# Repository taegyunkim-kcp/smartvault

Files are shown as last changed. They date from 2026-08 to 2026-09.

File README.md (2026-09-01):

# SmartVault (NFC Smart Vault MIL-S)

군부대 내무반용 스마트폰 보관함 IoT 시스템. 모노레포 구조.

## 레포 구조

```
smartvault/
├── hardware/          # 게이트웨이 보드 KiCad 프로젝트 (회로도/PCB)
├── firmware/          # Arduino MCU 펌웨어 (RFID×10 리더, 잠금장치 제어)
├── gateway-bridge/    # 건물별 Concentrator - RS485 ↔ 중앙서버 브리지 (Python)
├── backend/           # API 서버 (Node/Express + MySQL)
├── frontend/          # 관리자 대시보드 (React)
└── docs/              # 아키텍처/온보딩/프로토콜/설계 문서
```

## 개발 시작하기 (Windows)

자세한 설치 절차는 `docs/dev-environment-setup.md` 참고. 요약:

```powershell
# 1. DB 컨테이너 기동 (개발용)
docker compose -f docker-compose.dev.yml up -d

# 2. 백엔드
cd backend
copy .env.example .env.development
npm install
npm run dev

# 3. 프론트엔드
cd ../frontend
npm install
npm run dev
```

## 개발/운영 환경 분리 원칙

이 PC 한 대에서 개발과 운영을 동시에 돌립니다. **절대 같은 포트·같은 DB를 쓰지 않습니다.**

| | 개발(dev) | 운영(prod) |
|---|---|---|
| 백엔드 포트 | 4000 | 4001 |
| 프론트엔드 포트 | 3000 (vite dev server) | 3001 (정적 빌드 서빙) |
| DB 포트 | 3307 (Docker) | 3308 (Docker) |
| DB 이름 | smartvault_dev | smartvault_prod |
| 환경변수 파일 | `.env.development` | `.env.production` |
| 실행 방식 | `npm run dev` (터미널, 코드 수정 시 자동 재시작) | PM2로 백그라운드 상시 구동 |

자세한 내용은 `docs/dev-environment-setup.md` 참고.

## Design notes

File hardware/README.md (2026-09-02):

# hardware — 보관함 게이트웨이 KiCad 프로젝트

Arduino UNO 게이트웨이 보드의 회로도/PCB 원본. 같은 디렉토리의 `CLAUDE.md`가 이
설계를 검토·확정한 뒤 요약한 문서이므로, **핀맵/넷 이름 등은 그 문서를 표준으로 삼고**,
실제 배선의 세부(부품값, 커넥터 핀아웃 등)를 확인할 땐 여기 KiCad 파일을 연다.

## 구성

- `kicad/smartvault.kicad_pro` — 프로젝트 파일, KiCad로 이걸 연다.
- `kicad/smartvault.kicad_sch` — 최상위 시트. 아래 서브시트를 계층적으로 포함:
  - `DEVid-Buzz.kicad_sch` — 74HC165 장치ID + 부저
  - `DoorRock-drv.kicad_sch` — 도어락 구동
  - `MFRC522_Conn.kicad_sch` — RFID 리더 10개 커넥터 + 74LVC138A 디코더 뱅크
  - `power.kicad_sch` — 12V→5V/3.3V 전원부
  - `RS485-com.kicad_sch` — MAX13487E RS485 트랜시버
  - `RST-wDog.kicad_sch` — ATtiny13A 워치독/리셋 회로
- `kicad/smartvault.kicad_pcb` — PCB 레이아웃(아직 초기 단계 — 배치/라우팅 미완료일 수 있음)
- `kicad/s_vault.kicad_sym` — 커스텀 심볼 라이브러리(이 프로젝트 전용으로 그린 부품 심볼).
  원본: `D:\pcb\smartvault-pcb-1\s_vault.kicad_sym`. `RS485-com.kicad_sch`/`power.kicad_sch`가
  이 라이브러리의 심볼을 참조한다.
- `kicad/footprint.xlsx` — 부품-풋프린트 매핑 스프레드시트(2026-09-02 추가)

## 원본 출처

**작업은 이 PC의 `D:\pcb\회로도 편집 완료\`에서 KiCad로 직접 한다.** `Z:\HDD2\pcb 설계\`는
집 밖에서 작업할 때 쓰는 공유 드라이브로, D:의 내용을 그대로 미러링한다 — 두 경로
내용이 다르면 **D:을 기준으로 삼을 것**(2026-09-02 확정).

현재 버전(2026-09-02 기준): `D:\pcb\회로도 편집 완료\20260901_ver01\`. 원본 프로젝트
파일명은 `20260901_ver01.kicad_*`이지만, 저장소 안에서는 계속 `smartvault.kicad_*`로
통일했다(작업 폴더에 날짜/버전을 붙이는 건 원본 쪽 관례일 뿐 — git이 버전을 관리하므로
저장소 파일명까지 따라 바꾸지 않는다. 파일 내부에 프로젝트명을 참조하는 부분
(`(project "...")`, `.kicad_pro`의 filename 필드 등)은 전부 `smartvault`로 바꿔서
복사했다).

원본 작업 폴더 이름 자체가 버전마다 바뀌어왔다(`smartvault-pcb-1/smartvault/` →
`회로도 편집 완료/20260901_ver01/`) — 다음에 갱신할 때 폴더 구조가 또 바뀌었을 수
있으니 `D:\pcb\` 아래를 먼저 훑어서 최신 폴더를 확인할 것.

**이 저장소의 사본은 스냅샷이다** — 실제 설계가 바뀌면 원본에서 다시 복사해서 갱신해야
하고, 그때마다 같은 디렉토리의 `CLAUDE.md`도 같이 확인해서 핀맵이 안 어긋나게 맞출 것
(`CLAUDE.md` 7장 "변경 이력 관리 원칙" 그대로 적용).

상세 설계 문서(회로도 이미지 포함)는 `docs/SmartVault_Design_Document.docx`도 같이 참고.

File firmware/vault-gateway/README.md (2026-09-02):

# vault-gateway — 보관함 게이트웨이(Arduino UNO) 펌웨어

내무반 1개당 1대 설치되는 컨트롤러 보드 펌웨어. 핀맵/하드웨어 확정 스펙은
`hardware/CLAUDE.md` 1장을 따른다 — 핀 번호를 바꿔야 하면 그 문서를 먼저 고치고 `pins.h`를 맞출 것.

## 레거시 참고 코드

`Z:\HDD2\스마트폰보관함\1. 일반\mcuProgram\ver1_2_1_close_reading_only_white_MCU_20250204`
(가장 최신 버전, 파일명 날짜 기준)가 실전에서 쓰인 이전 보드 펌웨어다. 여기서 실제로
가져온 값/로직:
- 도어락 개방 펄스 2000ms, LOCK_STATE 극성(LOW=닫힘) — `door_lock.cpp`
- 버튼은 "지금 닫혀 있을 때만" 먹는다 — `door_lock.cpp`
- 카드 인식 멜로디(G7,G7,G5,G5 각 ~31ms) — `buzzer.cpp`
- 내장 AVR 워치독(`wdt_enable(WDTO_2S)`, RS485 바이트 수신 시에만 `wdt_reset()`) — `vault-gateway.ino`

의도적으로 안 가져온 것: 리더 CS 방식(레거시는 리더당 GPIO 10개 직결, 이 보드는
74LVC138A 디코더라 배선 자체가 다름)과 통신 프레임 포맷(레거시는 가변 구분자 텍스트,
여기는 고정 길이+체크섬으로 재설계 — `docs/architecture.md` 5장이 원래 그렇게 하라고
명시한 부분).

## 상태 (v0 초안, 2026-09-02)

**컴파일 확인 완료** — `arduino-cli` 1.5.1 + `arduino:avr` 1.8.8 + `MFRC522` 1.4.12로
`arduino:avr:uno` 대상 컴파일, `--warnings all`에서도 경고 0개. 스케치 9894바이트(30%),
전역변수 488바이트(23%) 사용. 재현하려면:

```powershell
arduino-cli core install arduino:avr
arduino-cli lib install MFRC522
arduino-cli compile --fqbn arduino:avr:uno --warnings all firmware/vault-gateway
```

컴파일만 확인한 것이고 **실제 보드에서 동작을 검증한 적은 없음** — RFID 리더/도어락 없이는
`rfid_mux`/`door_lock`이 실제 하드웨어와 맞물려 도는지 알 수 없다. 업로드 전 벤치 테스트 필수.

## 필요한 라이브러리 (Arduino IDE 라이브러리 매니저)

- `MFRC522` (miguelbalboa/rfid) — RFID 리더 제어
- `SoftwareSerial`, `SPI` — 아두이노 코어 내장, 별도 설치 불필요

## 보드 설정

- 보드: Arduino UNO
- 업로드: USB(소켓 마운트된 UNO에 직접) — PlatformIO 아님, Arduino IDE로 이 폴더를 스케치로 열기

## 모듈 구성

| 파일 | 역할 |
|---|---|
| `pins.h` | 핀맵 상수 (근거: hardware/CLAUDE.md 1장) |
| `gateway_identity.h` | **설치자가 직접 편집**하는 `GATEWAY_GROUP_ID`(2글자) — DIP주소와 합쳐 4글자 게이트웨이 ID를 만든다 |
| `device_id.*` | 74HC165 DIP 스위치 8비트 읽기 (부팅 시 1회) |
| `rfid_mux.*` | 74LVC138A 디코더로 리더 선택. **"새 카드 이벤트"가 아니라 "지금 상태 조회"** — 호출될 때마다 그 리더를 재초기화해서 계속 거치 중인 카드도 매번 다시 감지되게 함(스마트폰이 슬롯에 몇 시간씩 거치돼 있어도 실시간 상태를 알아야 하므로). **MFRC522 라이브러리의 SS 핀 토글은 실제 배선과 무관** — 진짜 선택은 이 모듈이 디코더 주소로 미리 해둔다 |
| `rs485_link.*` | 집중장치와의 프레임 송수신. **명령 없이 스스로 아무것도 안 보냄**(자동 하트비트 없음 — 여러 게이트웨이가 한 버스를 쓰므로 버스 충돌 방지). `READEROP='R'`로 콕 집어 물어볼 때만 도어 상태+리더 상태를 한 번에 응답, 브로드캐스트로 온 'R'은 무시. check_in/check_out 판단은 안 하고 현재 상태만 보고, 부저도 안 울림(서버 보고용과 로컬 확인음은 별개) (`firmware/docs/protocol-spec.md` 참고) |
| `door_lock.*` | 도어락 구동/버튼/센서, **fail-secure 정책** (통신 두절 시 무조건 잠금). 펄스 길이/극성/버튼 가드는 레거시에서 검증된 값 |
| `presence_watch.*` | 문이 열려 있는 동안 **게이트웨이가 스스로** 리더를 순회하며, 빈 자리에 폰이 새로 놓이는 순간에만 확인 부저(뺄 땐 무음). RS485/서버와 무관한 순수 로컬 로직이라 통신 두절 중에도 동작 |
| `buzzer.*` | 부저 — 카드 인식 멜로디는 레거시 값 그대로, 나머지는 placeholder |
| `vault-gateway.ino` | `setup()`/`loop()` — 위 모듈을 엮음. 내장 AVR 워치독도 여기서 관리 |

## 알려진 미해결 항목

1. **실제 하드웨어에서는 미검증** — 컴파일만 확인됨(위 참고). 실물 리더/락 붙여서 동작 테스트 필요.
2. **ATtiny13A 워치독 펌웨어** — 완전히 별개 프로젝트(ISP로 직접 굽고 소켓에 꽂음, 여기 스케치와 무관). 아직 시작 안 함.
3. **도어락 펄스/센서 극성 재확인 권장** — 레거시 값(2000ms, LOW=닫힘)을 그대로 가져왔지만, 배선판이 바뀐 새 보드에서 벤치로 한 번은 재확인 권장(`door_lock.cpp` 상단 주석).
4. **RESET 필드(전체 재부팅류) 미연결** — 프로토콜상 파싱은 하지만 아직 실제 동작에 안 이어짐(`rs485_link.cpp`의 `(void)resetScope`).
5. **집중장치(`gateway-bridge/`) 쪽 파서 + check_in/check_out diff 로직 미구현** — 지금 이 펌웨어가 보내는 `:RD:...:PRESENT:...` 응답을 실제로 받아서 리더별 마지막 상태와 비교해 입고/출고 전환을 만드는 코드가 반대편에 아직 없다(`bridge/protocol_parser.py` 없음). 이 diff는 **집중장치가 기본 담당**, 서버 이벤트 관리와 연계해서 확장 가능하게 만들기로 확정(2026-09-02).
6. **개방/오류 부저 톤** — placeholder(레거시엔 대응 패턴 없음). 카드 인식 멜로디만 레거시 검증값.
7. **폴링 주기/명령 간격 실측 필요** — `protocol-spec.md`의 타이밍 수치는 보레이트 계산만 한 추정치, 실물 리더 스캔 시간 미측정.

## 게이트웨이 ID ↔ gateway_id 매핑 (2026-09-02 확정, 상세는 protocol-spec.md)

DIP 스위치(8비트)만으로는 버스 하나 안에서만 유일해서, `gateway_identity.h`의
`GATEWAY_GROUP_ID`(설치자가 하드웨어/펌웨어 배치별로 편집하는 2글자 상수)와 합쳐
4글자 원시 ID를 만들어 RS485로 전달한다. 이건 최종 `gateway_id`(`"1CORPS-B3-R204-G1"`
같은 문자열)가 아니다 — **로컬 설정 파일로 미리 매핑을 만들어두지 않는다.** 대신 이미
있는 관리자 등록 플로우(`detected_gateways` → `GatewayListPage.jsx`에서 매칭 → `gateways`
정식 등록)를 그대로 재사용한다: 집중장치는 미등록 원시 ID를 그대로 서버에 올리고,
관리자가 방과 매칭하면 그 결과를 집중장치가 캐시해서 이후 보고에 쓴다. 이 캐싱/동기화
로직 자체는 아직 `gateway-bridge` 쪽에 없다(다음 단계).

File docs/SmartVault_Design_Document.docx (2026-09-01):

SmartVault — NFC/RFID 스마트폰 보관함 잠금장치

전체 회로도 설계 문서 (KiCad 실제 회로 기준) | Rev. B | 2026-09-01

본 문서는 KiCad로 작성된 실제 회로도(루트 시트 + 6개 서브시트)를 기준으로 설계 의도와 동작 원리를 정리한 것입니다. 각 시트별로 회로 설명과 BOM을 수록하고, 문서 마지막에 전체 부품을 지정자순으로 통합한 BOM을 별도로 정리했습니다.

# 1. 시스템 종합 개요

## 1.1 용도 및 전체 구성

이 보드는 다수의 스마트폰 보관함(사물함)에 하나씩 설치되는 컨트롤러로, RS485 멀티드롭 버스로 상위 서버와 통신하며 다음 기능을 수행합니다: ① NFC/RFID 카드로 보관함 슬롯(최대 10개) 사용자 인식, ② 전자 도어락 개폐 제어 및 상태 감지, ③ RS485를 통한 서버와의 명령/응답 송수신, ④ 통신 두절 시 자동 복구(워치독), ⑤ DIP 스위치를 통한 현장 설정(장치 ID, RS485 종단/바이어스, 도어락 전압).

두뇌 역할은 Arduino UNO(소켓 마운트)가 담당하며, 보조로 ATtiny13A 기반 워치독 MCU가 UNO의 무응답을 감시합니다. 전원은 12V 어댑터 하나로 입력받아 보드에서 5V/3.3V를 자체 생성합니다.

## 1.2 전체 신호 흐름

12V_IN → [Sheet1 전원부] → 5V_RAW / 3V3_RAW 생성 → Arduino UNO(MCU) → 각 서브시스템(Sheet2 도어락, Sheet3 RS485, Sheet5 RFID×10, Sheet6 장치ID/부저) 제어 → Sheet4 워치독이 RS485 수신 활동을 감시하며 무응답 시 UNO를 리셋/재부팅

## 1.3 핵심 설계 원칙

- 무인 운영 안정성 — 2단계 워치독: RS485 수신 활동이 일정 시간 끊기면 1단계로 UNO를 소프트 리셋(RESET 핀 풀다운)하고, 그래도 복구되지 않으면 2단계로 전원 자체를 완전히 껐다 켜는 콜드리셋을 수행합니다(Sheet1의 로드스위치 Q1을 Sheet4의 H_Reset 신호로 제어).
- 아두이노 핀 절약 — RFID 리더 10개의 칩셀렉트(CS)를 74LVC138A 디코더 2개로 압축해 4핀(주소 3비트+뱅크선택)만 사용하고, 장치 ID(8비트)는 74HC165 시프트레지스터로 3핀만 사용합니다. 그 결과 UNO 20핀 예산 안에서 모든 기능을 수용하면서도 D10 등 여유 핀이 남습니다.
- 현장 설정 가능성 — RS485 종단저항(SW2)과 바이어스(SW3/SW4), 도어락 구동전압(SW1, 5V/12V 선택)을 전부 하드웨어 스위치로 두어, 설치 현장에서 펌웨어 재업로드 없이 구성을 맞출 수 있습니다.
- 유지보수성 — Arduino UNO와 워치독 MCU(ATtiny13A) 모두 소켓 마운트입니다. UNO는 USB로 직접 업로드하고, ATtiny13A는 별도 ISP 프로그래머로 미리 구운 뒤 소켓에 꽂아 사용해 보드에 별도 ISP 헤더가 필요 없습니다.
- 신호 무결성 — 5V(UNO)↔3.3V(MFRC522) 레벨 차이는 채널별 독립 트라이스테이트 버퍼(74LVC125A, 74AHCT1G125)로 처리해, 옥탈 트랜시버 한 개로 방향을 공유할 때 생기는 제약을 피했습니다. 모든 신호선에는 직렬저항을 두어 반사·노이즈에 대비했습니다.

# 2. Sheet 1 — 전원부 (power Sheet)

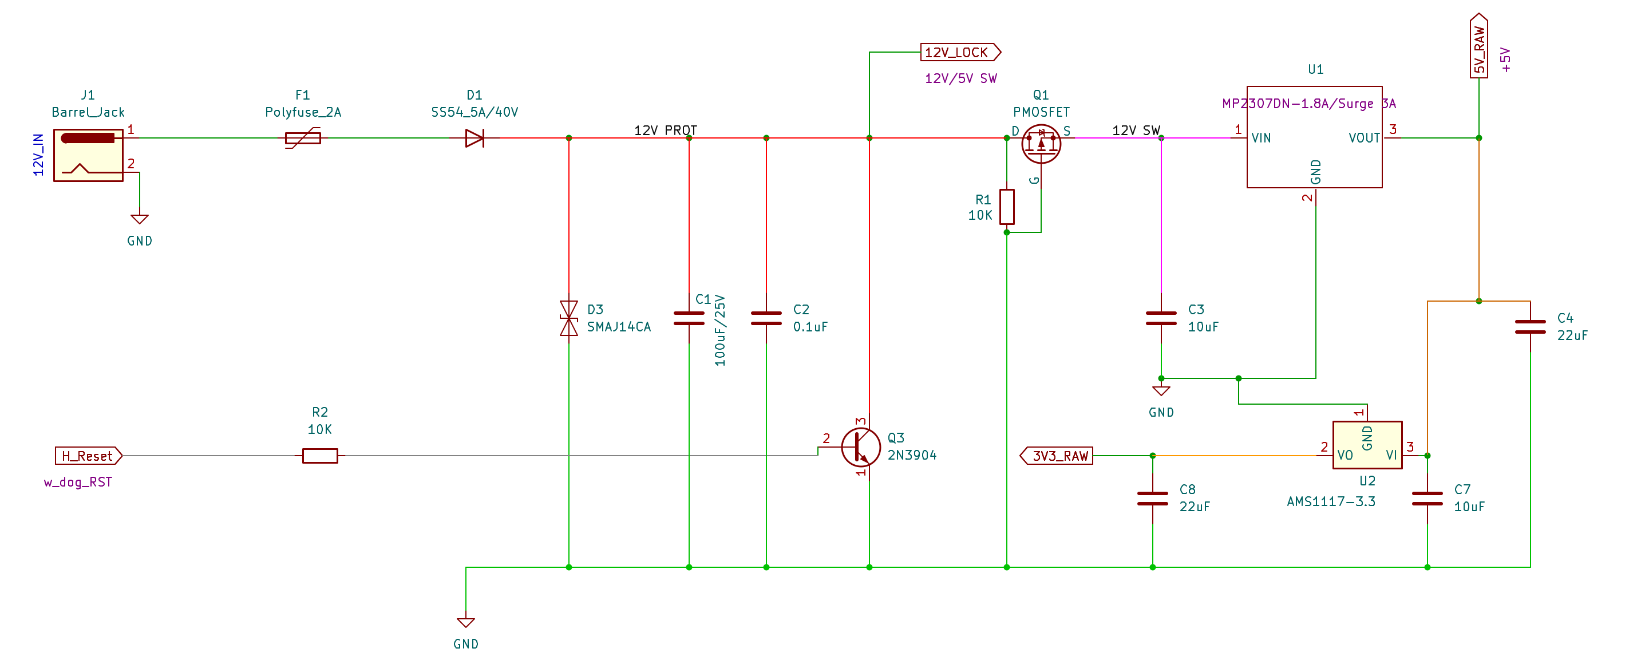
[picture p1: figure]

## 설계 설명

12V 어댑터 입력(J1)을 F1(2A 폴리퓨즈)과 D1(쇼트키, 역전압 방지)로 1차 보호한 뒤, D3(양방향 TVS)로 서지를 흡수하고 C1/C2로 벌크·고주파 디커플링을 한 넷이 12V_PROT입니다. 12V_LOCK은 이 12V_PROT 지점에서 곧바로 분기되므로, 뒤에 있는 로드스위치(Q1)가 꺼지더라도 도어락 전원은 항상 살아있습니다 — 콜드리셋 도중에도 도어락 상태가 끊기지 않도록 하기 위한 설계입니다.

Q1(P-MOSFET)은 12V_PROT과 12V_SW 사이의 로드스위치로, Q3(NPN)를 통해 워치독 신호(H_Reset)로 On/Off됩니다. H_Reset이 HIGH(평상시)면 Q3가 켜져 Q1 게이트가 LOW로 당겨져 Q1이 On되고, H_Reset이 LOW(워치독 2단계 트리거)가 되면 Q1이 Off되어 U1/U2 이후 전체 로직 전원이 완전히 차단됐다가 다시 켜집니다 — 진짜 콜드리셋입니다.

12V_SW는 U1(MP2307DN, 1.8A 지속/3A 서지 벅컨버터)에서 5V_RAW로 변환되고, 이 5V_RAW가 U2(AMS1117-3.3 LDO)를 거쳐 3V3_RAW가 됩니다. 5V_RAW는 UNO의 5V 핀에 직결(VIN 미사용)되어 온보드 리니어 레귤레이터의 발열을 피하고, 3V3_RAW는 MFRC522 10개 전용 전원으로 UNO 온보드 3.3V(약 50mA 한계)를 대체합니다.

## BOM

지정자 | 부품 | 정격/값 | 비고
J1 | DC 배럴잭 | Barrel_Jack | 12V_IN 입력
F1 | 폴리퓨즈 | 2A | 과전류 보호
D1 | 쇼트키 다이오드 | SS54 (5A/40V) | 역전압 보호
D3 | 양방향 TVS 다이오드 | SMAJ14CA | 서지 보호
C1 | 전해커패시터 | 100uF/25V | 12V 벌크 커패시턴스
C2 | 세라믹커패시터 | 0.1uF | 고주파 디커플링
Q1 | P채널 MOSFET | PMOSFET | 고전위측 로드스위치(콜드리셋)
R1 | 저항 | 10K | Q1 게이트 풀업
Q3 | NPN 트랜지스터 | 2N3904 | H_Reset 신호 반전 구동
R2 | 저항 | 10K | Q3 베이스 전류 제한
U1 | DC-DC 벅컨버터 | MP2307DN (1.8A 지속/3A 서지) | 12V→5V
C3 | 세라믹커패시터 | 10uF | U1 입력(VIN) 디커플링
C4 | 세라믹커패시터 | 22uF | U1 출력(5V_RAW) 디커플링
U2 | 3.3V LDO 레귤레이터 | AMS1117-3.3 | 5V_RAW→3V3_RAW
C5 | 세라믹커패시터 | 10uF | U2 입력(VI) 디커플링
C6 | 세라믹커패시터 | 22uF | U2 출력(VO/3V3_RAW) 디커플링

# 3. Sheet 2 — 도어락 구동부 (DoorRock-drv)

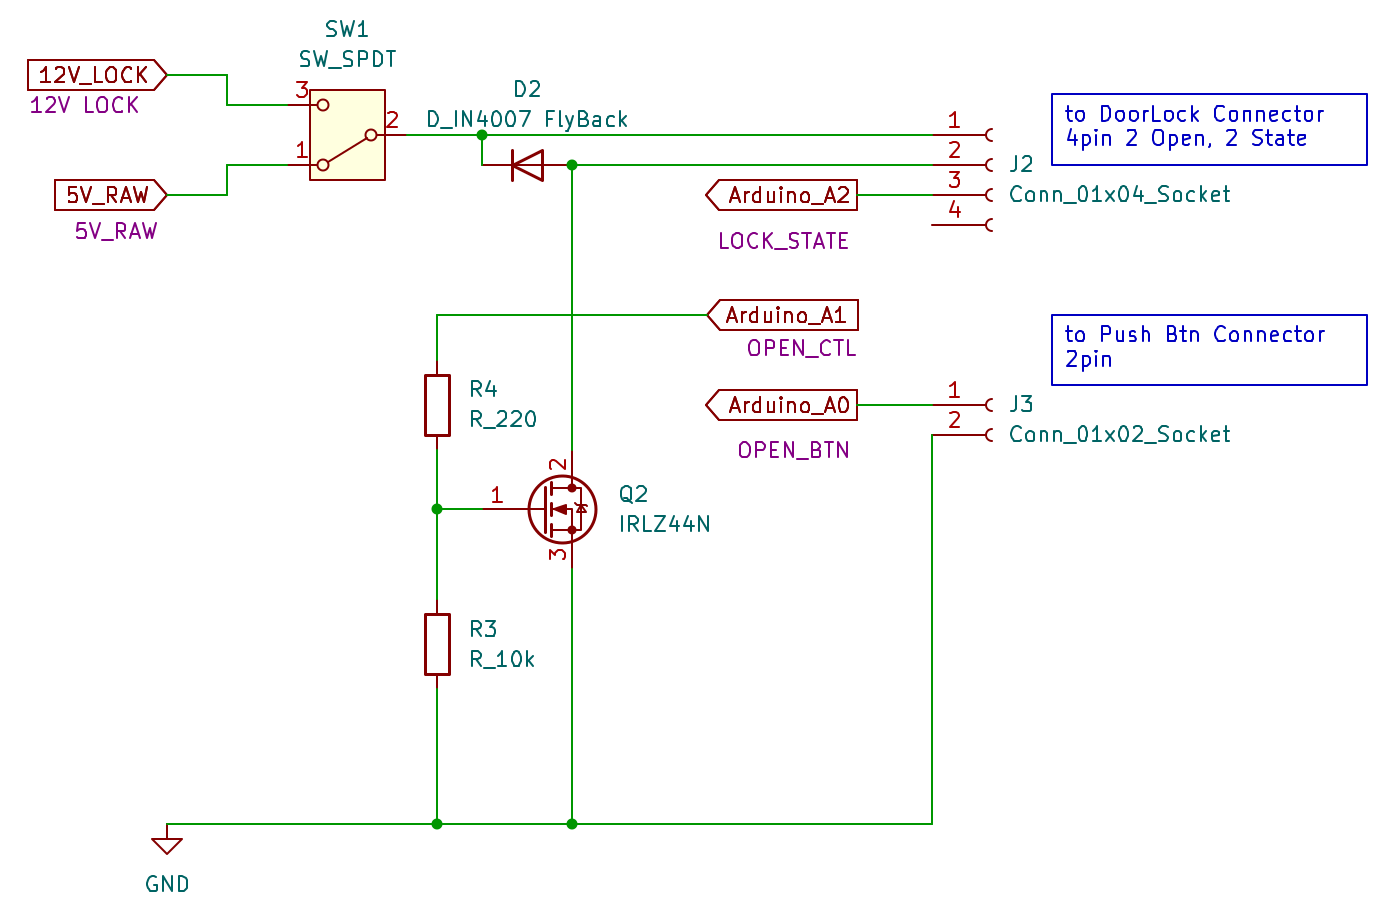
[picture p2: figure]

## 설계 설명

SW1(SPDT)로 도어락 구동전압을 12V_LOCK 또는 5V_RAW 중 하나로 설치 시 선택합니다. Q2(IRLZ44N, 로직레벨 N-MOSFET)가 저전위측 스위치로 도어락 솔레노이드를 구동하며, R4(220Ω)는 게이트 전류 제한, R3(10K)는 게이트 풀다운으로 부팅·리셋 중 하이임피던스 상태에서도 도어락이 오픈(오동작)되지 않도록 합니다. D2(1N4007)는 솔레노이드 역기전력을 흡수하는 플라이백 다이오드입니다.

J2(4핀)는 실제 도어락 어셈블리(솔레노이드+상태감지 스위치가 물리적으로 하나의 장치)로 나가는 커넥터로, LOCK 구동선 2개와 LOCK_STATE(상태감지, →A2) 및 GND로 구성됩니다. J3(2핀)는 로컬 개방 버튼(→A0)입니다. OPEN_CTL(A1)이 Arduino에서 Q2 게이트로 나가는 제어 신호이며, LOCK_STATE와 OPEN_BTN은 INPUT_PULLUP으로 별도 풀업저항 없이 스위치를 GND로 직결하는 방식입니다.

## BOM

지정자 | 부품 | 정격/값 | 비고
SW1 | 전압 선택 스위치 | SW_SPDT | 12V_LOCK ↔ 5V_RAW 중 1개 선택 — 동시 인가 금지
D2 | 정류 다이오드 | 1N4007 | 플라이백(역기전력) 보호
R4 | 저항 | 220Ω | Q2 게이트 전류 제한
R3 | 저항 | 10K | Q2 게이트 풀다운 — 부팅 중 오픈 방지
Q2 | N채널 로직레벨 MOSFET | IRLZ44N | 도어락 구동 스위치
J2 | 4핀 소켓 커넥터 | Conn_01x04_Socket | DoorLock — LOCK+/LOCK_RTN/LOCK_STATE(→A2)/GND
J3 | 2핀 소켓 커넥터 | Conn_01x02_Socket | Push Btn — OPEN_BTN(→A0)/GND

# 4. Sheet 3 — RS485 통신부 (RS485-com)

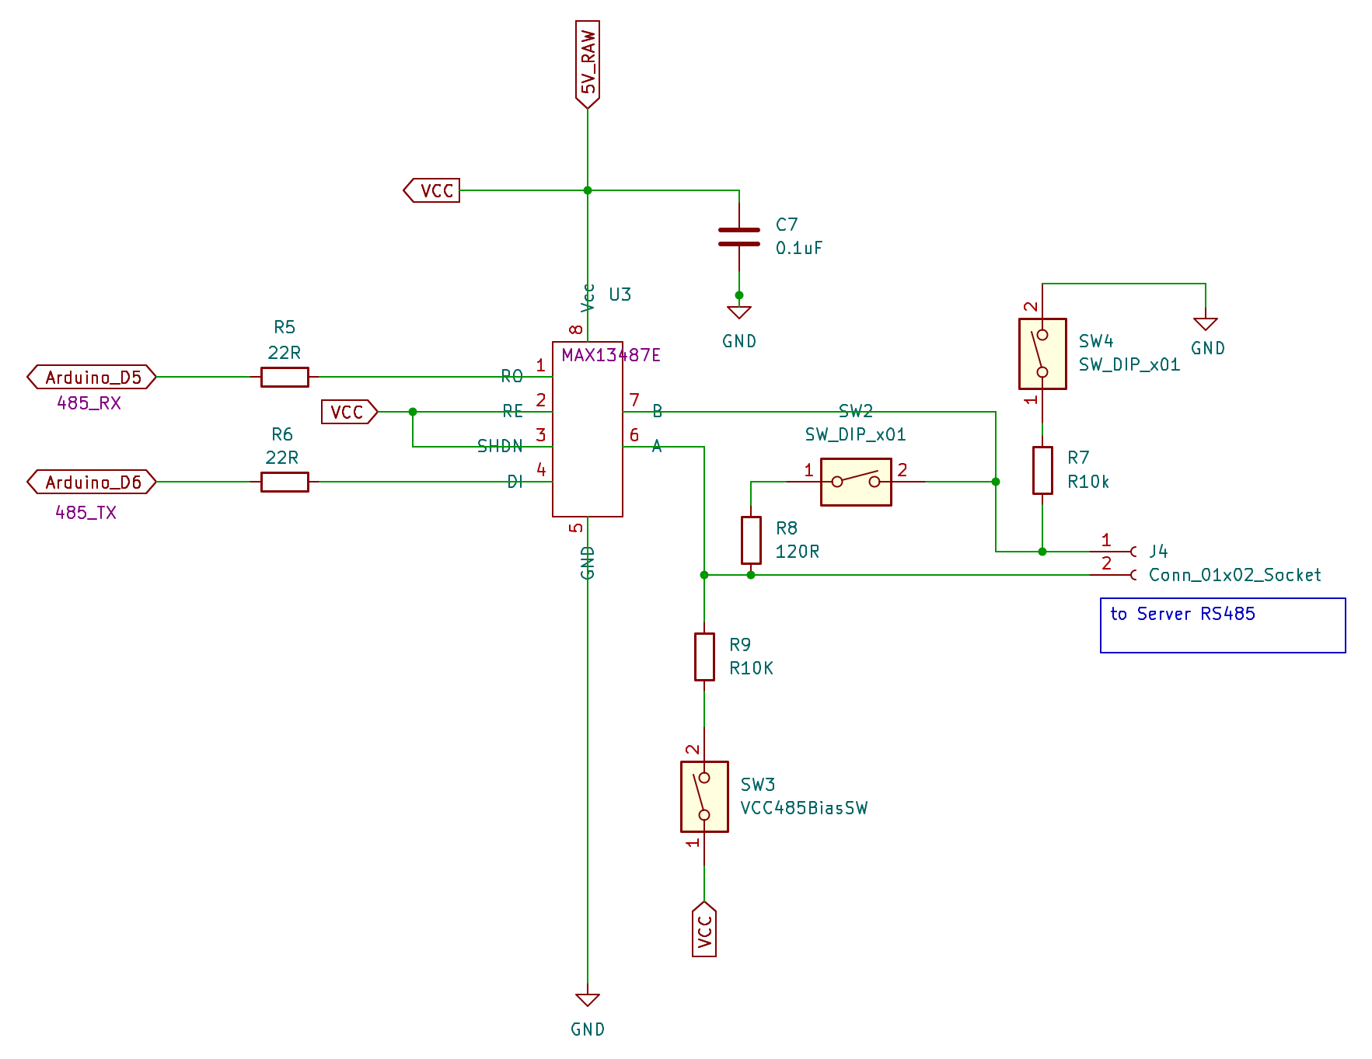
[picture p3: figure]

## 설계 설명

U3(MAX13487E)는 AutoDirection 기능이 내장된 RS485 트랜시버로, RE#·SHDN# 핀을 모두 VCC에 고정해두면 칩 내부 상태머신이 DI(송신 데이터) 활동을 스스로 감지해 버스 방향전환을 자동 처리합니다 — Arduino가 별도 GPIO로 방향을 제어할 필요가 없습니다. Arduino의 485_RX(D5)/485_TX(D6)는 R5/R6(22Ω)을 거쳐 U3의 RO/DI에 연결되며, C7(0.1uF)이 U3 VCC 바로 옆에서 디커플링을 담당합니다.

이 보드는 여러 보관함이 하나의 RS485 버스에 멀티드롭으로 물리는 구조이므로, 종단저항과 페일세이프 바이어스는 버스 전체에서 딱 한 곳(들)에만 필요합니다. R8(120Ω)이 A-B 사이의 종단저항이며 SW2(DIP)로 유효/무효화합니다 — 버스 양 끝단 노드만 켭니다. R9(10K, A라인→VCC 풀업)는 SW3으로, R7(10K, B라인→GND 풀다운)은 SW4로 각각 독립적으로 활성화하는데, 이 역시 버스 여러 노드 중 바이어스를 담당할 한 곳에서만 켜서 과도한 부하 없이 유휴 시 정형화된 유휴 전압을 유지합니다. J4가 실제 RS485 버스(서버 방향)로 나가는 A/B 2핀 커넥터입니다.

## BOM

지정자 | 부품 | 정격/값 | 비고
U3 | RS485 트랜시버 | MAX13487E | RE#/SHDN# 모두 VCC 고정, AutoDirection
R5 | 저항 | 22Ω | RO 직렬(신호보호)
R6 | 저항 | 22Ω | DI 직렬(신호보호)
C7 | 세라믹커패시터 | 0.1uF | U3 VCC 디커플링
R8 | 저항 | 120Ω | 버스 종단(A-B 간) — SW2로 유효화
R9 | 저항 | 10K | A라인 풀업 바이어스 — SW3로 인에이블
R7 | 저항 | 10K | B라인 풀다운 바이어스 — SW4로 인에이블
SW2 | DIP 스위치(1P) | SW_DIP_x01 | 종단저항 유효화 — 버스 끝단 노드만 ON
SW3 | 스위치(1P) | VCC485BiasSW | A라인 바이어스 인에이블 — 담당 노드만 ON
SW4 | DIP 스위치(1P) | SW_DIP_x01 | B라인 바이어스 인에이블 — 담당 노드만 ON
J4 | 2핀 소켓 커넥터 | Conn_01x02_Socket | to Server RS485 (A/B)

# 5. Sheet 4 — 리셋 / 워치독 (RST-wDog)

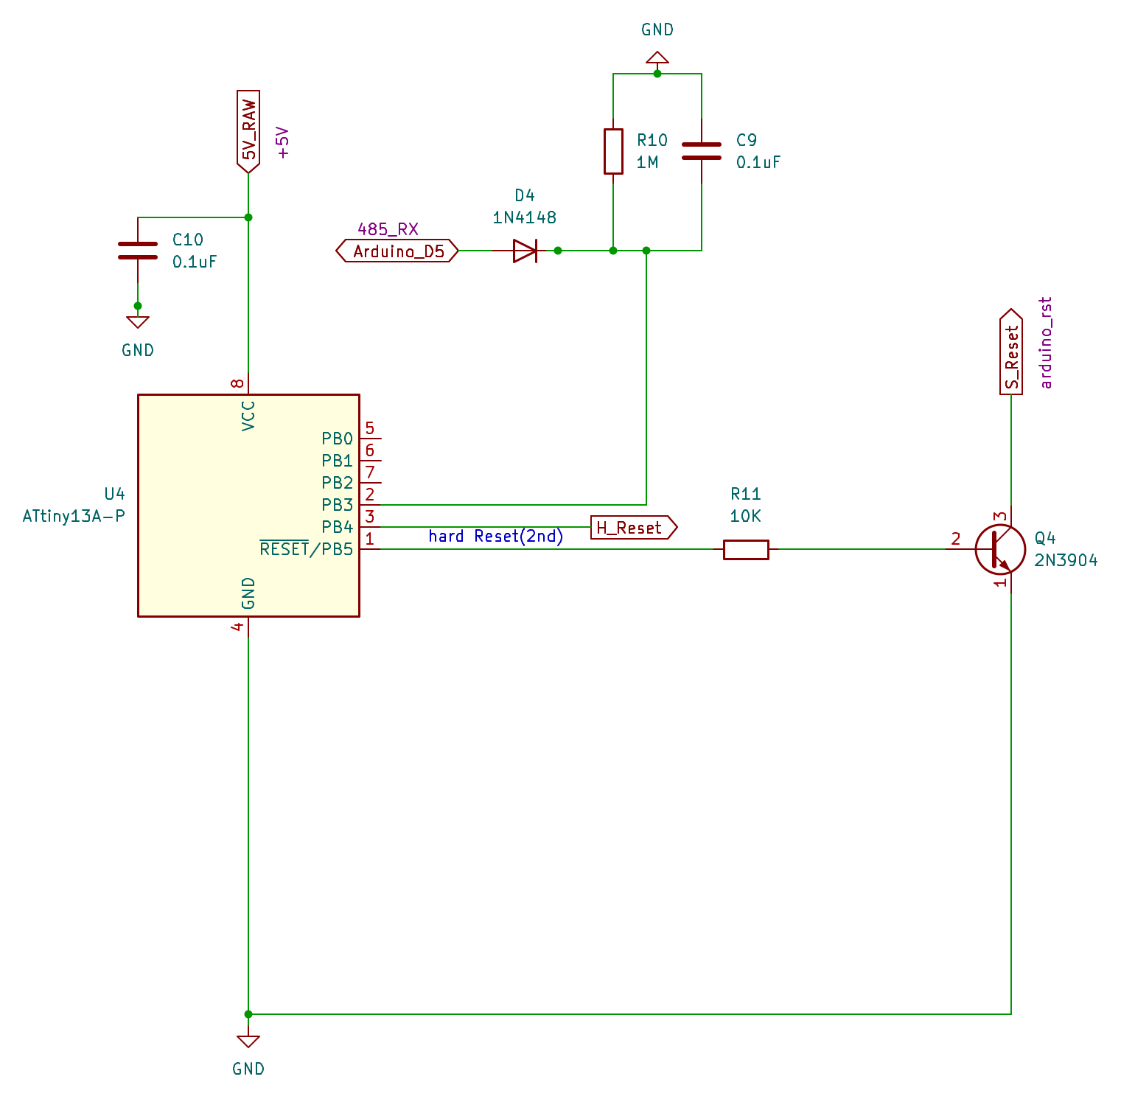
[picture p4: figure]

## 설계 설명

D4(1N4148)+R10(1M)+C9(0.1uF)는 485_RX(D5, RS485 수신선)의 펄스 활동을 감지하는 간이 피크검출 회로입니다. 통신 펄스가 들어올 때마다 C9가 충전되고, 일정 시간 펄스가 없으면 R10을 통해 서서히 방전됩니다. U4(ATtiny13A-P)가 이 전압(PB3)을 아날로그로 주기적으로 읽어, 전압이 임계값 밑으로 떨어지면(=한동안 통신이 없었다는 뜻) '무응답'으로 판단합니다.

2단계 대응 로직입니다. 1단계: 무응답 판정 시 U4의 PB4(H_Reset 넷)를 통해 자체적으로 처리하거나, PB5(RESET 겸용)를 통해 R11(10K)→Q4(2N3904)를 거쳐 Arduino의 RESET 핀(arduino_rst)을 짧게 풀다운해 소프트 리셋을 시도합니다. 2단계: 소프트 리셋을 여러 번 시도해도 통신이 복구되지 않으면, Sheet 1의 H_Reset 넷(=PB4 출력)을 LOW로 만들어 Q1 로드스위치 자체를 끄고 다시 켜는 콜드리셋(전원 완전 차단 후 재인가)을 수행합니다.

U4(ATtiny13A-P)는 DIP-8 소켓 실장입니다. 펌웨어는 이 보드가 아니라 별도 ISP 프로그래머(브레드보드 지그 등)에서 미리 구운 뒤 소켓에 꽂아 사용하는 방식으로, 보드 자체에는 ISP 헤더를 두지 않습니다. Arduino UNO 역시 소켓 마운트로, 두 MCU 모두 '보드에서 분리해 별도로 프로그래밍'하는 동일한 운용 방식을 취합니다.

## BOM

지정자 | 부품 | 정격/값 | 비고
U4 | 보조 감시 MCU | ATtiny13A-P (DIP-8) | 소켓 실장 — 별도 프로그래밍 후 장착. 1(RESET/PB5)=소프트리셋 출력, 2(PB3)=활동감지 입력, 3(PB4)=H_Reset(2단계) 출력, 8=VCC
D4 | 소신호 다이오드 | 1N4148 | 485_RX 활동감지 피크검출
R10 | 저항 | 1M | C9와 병렬(방전) — 타임아웃 시정수 결정
C9 | 세라믹커패시터 | 0.1uF | 활동감지 피크홀드
C10 | 세라믹커패시터 | 0.1uF | U4 VCC 디커플링(VCC-GND 최대한 근접 배치)
R11 | 저항 | 10K | Q4 베이스 전류 제한
Q4 | NPN 트랜지스터 | 2N3904 | Arduino RESET 핀(arduino_rst) 풀다운 — 소프트 리셋

# 6. Sheet 5 — RFID 리더부 (MFRC522_Conn)

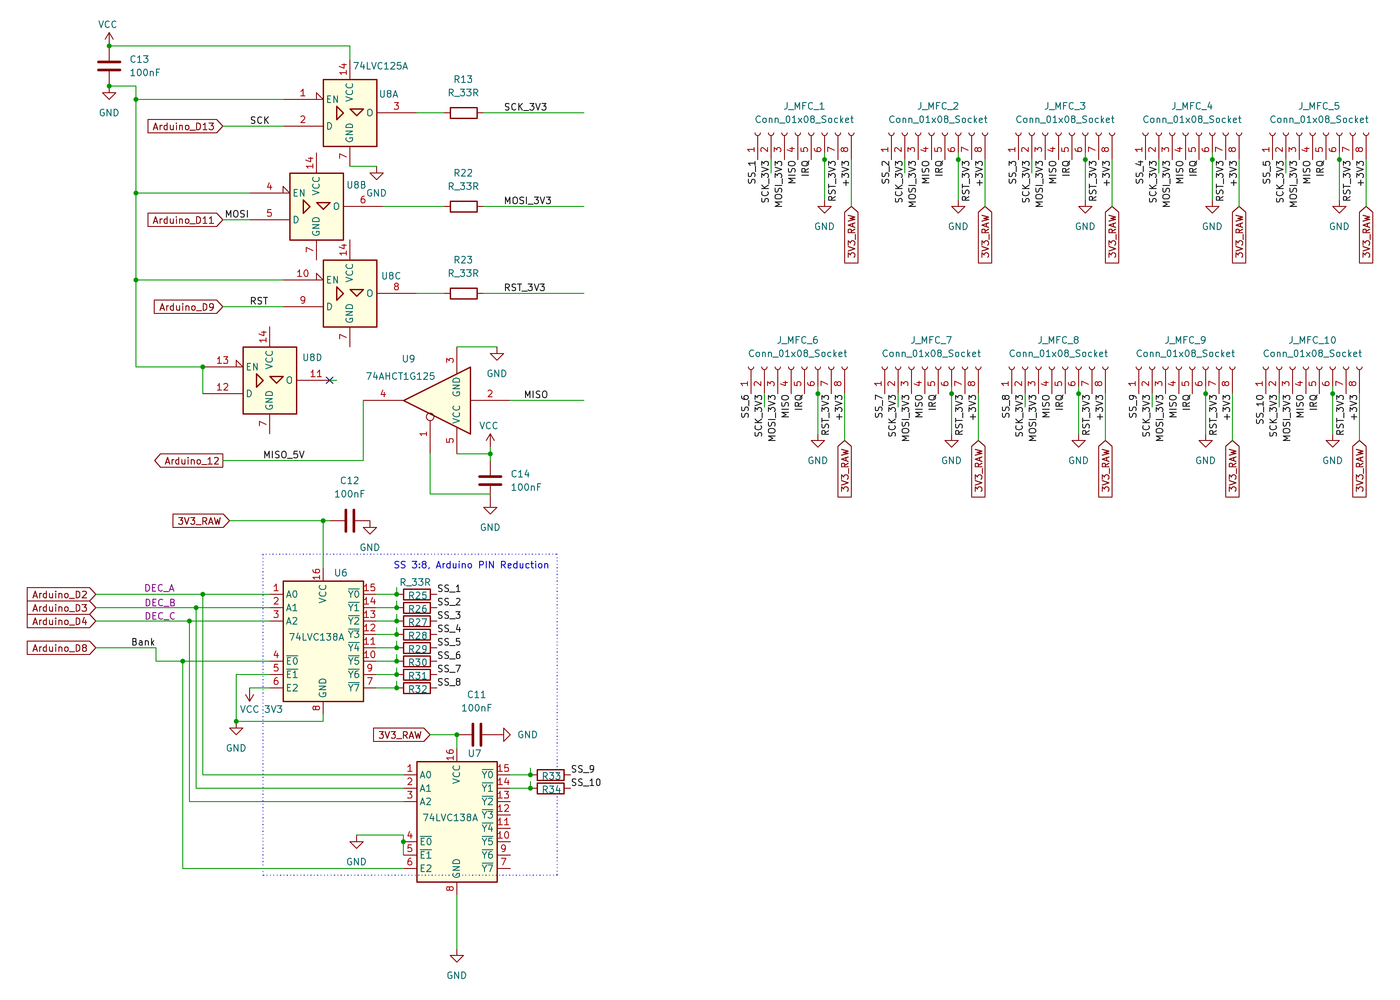
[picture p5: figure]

## 설계 설명

MFRC522(3.3V 전용 로직) 10개를 5V UNO와 연결하기 위한 레벨시프트를, 채널마다 독립 인에이블을 갖는 트라이스테이트 버퍼로 구성했습니다. U8(74LVC125A, 쿼드 버퍼)의 3개 게이트가 SCK/MOSI/RST를 5V→3.3V로 각각 버퍼링하며(EN 전부 GND 고정, 상시 출력), R13/R22/R23(33Ω)이 각 출력에 직렬로 붙어 신호를 보호합니다. 4번째 게이트는 예비(NC)입니다. MISO(3.3V→5V 방향)는 U9(74AHCT1G125, 단일 버퍼)로 별도 처리합니다 — 옥탈 트랜시버 한 개로는 방향이 반대인 신호를 동시에 처리할 수 없고, 리더 10개가 병렬로 물린 MISO 버스는 부하가 커서 능동 버퍼링이 신호 무결성에 유리합니다.

가장 중요한 구조적 특징은 칩셀렉트(SS/CS) 절감입니다. 리더 10개 각각에 아두이노 핀을 하나씩 배정하면 10핀이 필요하지만, 74LVC138A(3:8 디코더) 2개(U6=SS_1~8, U7=SS_9~10)로 대체해 DEC_A/B/C(3비트 주소, D2~D4)와 Bank(뱅크선택, D8) 단 4핀만으로 10개 CS를 전부 제어합니다. U7은 U6과 다른 인에이블 핀(E2)에 Bank를 연결해, 별도 인버터 없이도 Bank 신호 하나로 두 디코더를 상호 배타적으로 전환합니다. 디코더 출력마다 33Ω 직렬저항(R25~R32, R33/R34)을 두었습니다.

J_MFC_1~10은 각 리더로 나가는 8핀 커넥터로, SS_x(개별)/SCK_3V3/MOSI_3V3/MISO/IRQ/RST_3V3/GND/+3V3 순입니다. SCK/MOSI/MISO/RST/GND/+3V3 6개 신호는 10개 커넥터에 공통 병렬 배선되고 SS_x만 커넥터별 개별 배선입니다. IRQ(인터럽트)는 커넥터에 존재하지만 현재 버전에서는 MCU 쪽에 연결되어 있지 않은 예비 핀입니다.

## BOM

지정자 | 부품 | 정격/값 | 비고
U8 | 쿼드 트라이스테이트 버퍼 | 74LVC125A | SCK/MOSI/RST 버퍼링(3게이트 사용, 1게이트 NC). EN 전부 GND 고정
U9 | 단일 트라이스테이트 버퍼 | 74AHCT1G125 | MISO 버퍼(3.3V→5V)
U6, U7 | 3:8 라인 디코더 ×2 | 74LVC138A | SS_1~8(U6)/SS_9~10(U7) — 아두이노 4핀(D2/D3/D4/D8)으로 10개 CS 제어
R13, R22, R23 | 저항 | 33Ω | SCK_3V3/MOSI_3V3/RST_3V3 직렬
R25~R32 | 저항 ×8 | 33Ω | U6 출력(SS_1~8) 직렬
R33, R34 | 저항 ×2 | 33Ω | U7 출력(SS_9~10) 직렬
C11, C12, C13, C14 | 세라믹커패시터 ×4 | 100nF | U6/U7/U8/U9 VCC 디커플링
J_MFC_1~10 | 8핀 소켓 커넥터 ×10 | Conn_01x08_Socket | SS_x/SCK_3V3/MOSI_3V3/MISO/IRQ/RST_3V3/GND/+3V3

# 7. Sheet 6 — 장치 ID / 부저 (DEVid-Buzz)

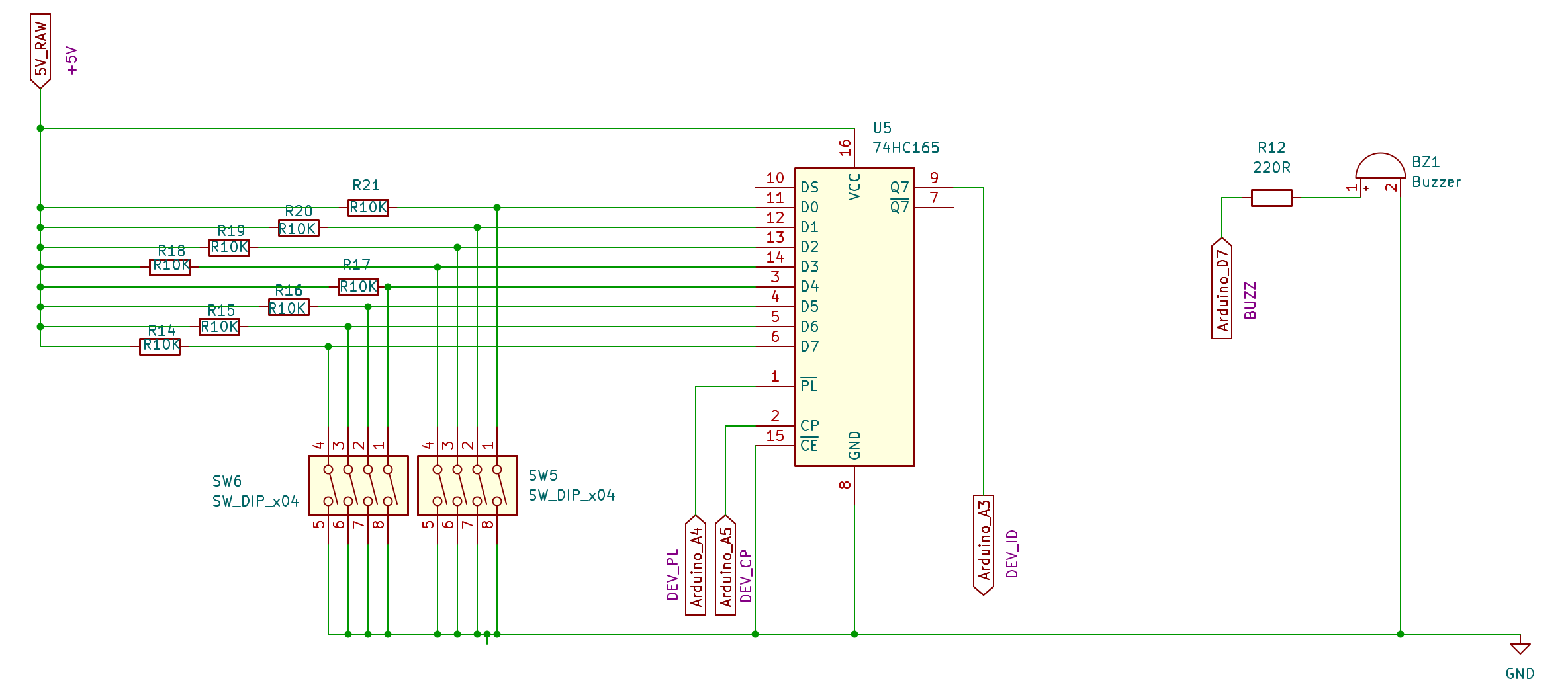
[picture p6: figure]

## 설계 설명

U5(74HC165, 8bit PISO 시프트레지스터)가 8개의 DIP 스위치(SW5+SW6, 4채널×2팩)로 설정한 장치 ID를 읽어들입니다. 각 데이터 입력(D0~D7)은 R14~R21(10K)로 풀업되어 있고, DIP 스위치가 그 입력을 선택적으로 GND에 연결해 0/1 값을 만듭니다. PL(래치, ←A4/DEV_PL)과 CP(클럭, ←A5/DEV_CP)를 아두이노가 전용 핀으로 직접 제어하고, Q7(시리얼 출력)이 A3(DEV_ID)로 들어와 8비트 값을 순차적으로 읽습니다. CE(칩 인에이블)는 GND 고정으로 상시 활성 상태입니다.

이전 설계 검토 과정에서는 PL/CP를 다른 신호(RST/SCK)와 공유하고 A4를 부팅 시에만 잠깐 빌려 쓰는 핀 절약 트릭을 검토했었으나, Sheet 5에서 디코더 방식으로 전환하며 핀 여유가 생겨 이번 실제 회로에서는 PL/CP/Q7을 각각 전용 핀(A4/A5/A3)으로 단순하고 안전하게 배정했습니다.

BZ1(피에조 부저)은 Arduino_D7(BUZZ)에서 R12(220Ω) 직렬저항을 거쳐 직접 구동됩니다. UART RX/TX가 D0/D1이 아니라 D5/D6으로 재배정되었기 때문에, 이전 설계에서 필요했던 'D0-부저 간 디버그 분리 스위치'는 이 회로에서 더 이상 필요 없습니다.

## BOM

지정자 | 부품 | 정격/값 | 비고
U5 | 8bit PISO 시프트레지스터 | 74HC165 | PL←A4(DEV_PL), CP←A5(DEV_CP), Q7→A3(DEV_ID), CE=GND 고정
R14~R21 | 저항 ×8 | 10K | U5 D0~D7 풀업
SW5, SW6 | DIP 스위치 ×2 | SW_DIP_x04 | 8채널 = 장치 ID 8비트(D0~D7)
R12 | 저항 | 220Ω | 부저(BZ1) 전류 제한
BZ1 | 피에조 부저 | Buzzer | Arduino_D7(BUZZ) 직접 구동

# 8. MCU 시트 (루트) — Arduino UNO 및 핀맵

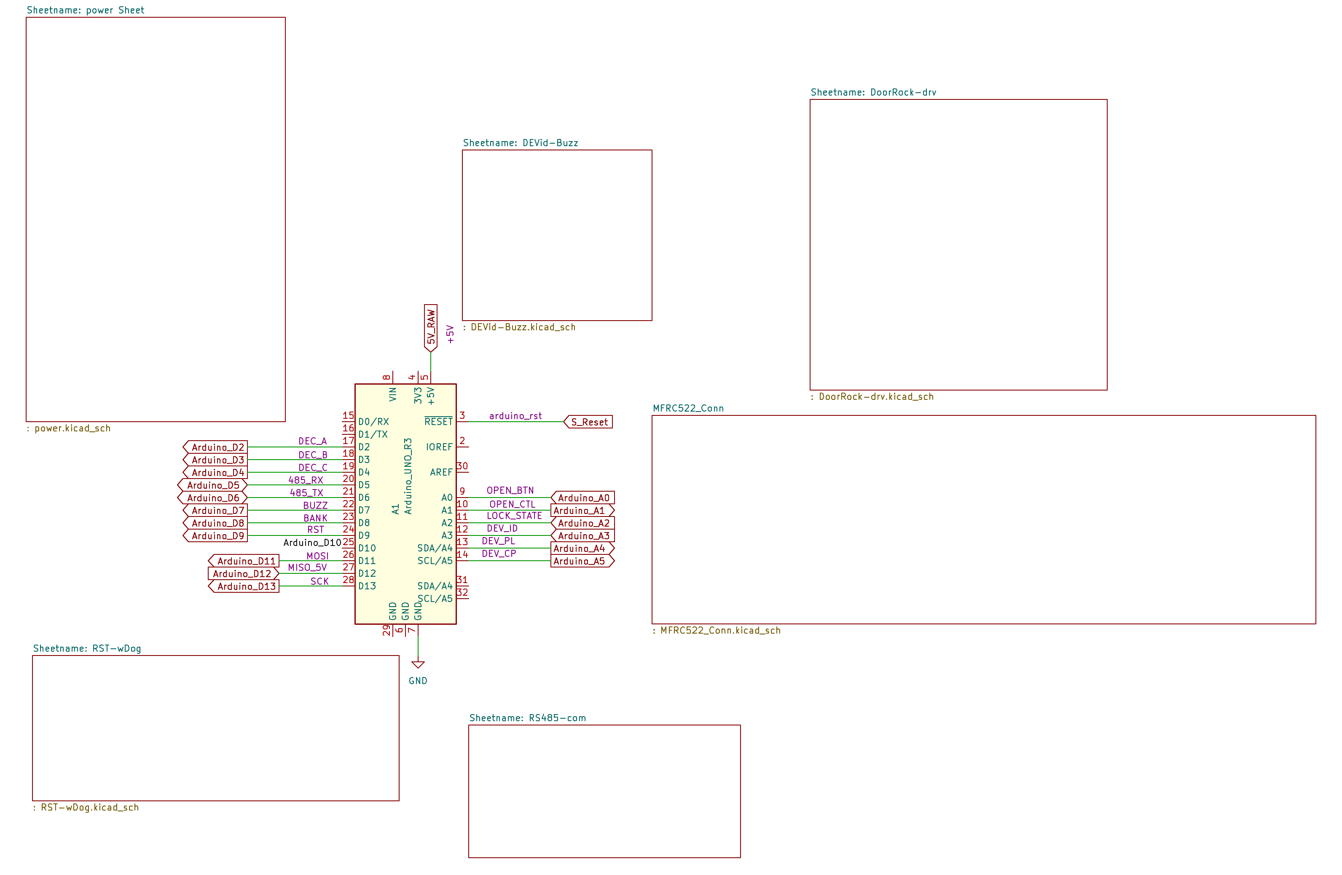
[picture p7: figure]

## 설계 설명

Arduino UNO(A1, Arduino_UNO_R3, 소켓 마운트)는 별도 서브시트가 아니라 KiCad 프로젝트의 루트 시트에 직접 배치되어 있습니다. UNO는 6개 서브시트 전부와 신호를 주고받는 '허브' 부품이라, 계층 라벨이 아니라 전역 라벨(Global Label)로 각 서브시트와 이름만으로 연결됩니다 — 그래서 루트 시트의 서브시트 박스들에는 개별 핀이 표시되지 않습니다.

전원은 5V 핀 하나로만 공급됩니다(5V_RAW). VIN은 사용하지 않는데, VIN에 12V를 직접 넣으면 UNO 온보드 리니어 레귤레이터가 전압차(12V-5V=7V)를 전부 열로 날리게 되어, Sheet 1의 효율 좋은 스위칭 벅컨버터(U1)로 미리 5V를 만들어 5V 핀에 직결하는 방식을 택했습니다. 마찬가지 이유로 온보드 3.3V 핀도 미사용이며(용량 약 50mA로 MFRC522 10개를 감당 못함), 대신 Sheet 1의 U2(AMS1117-3.3, ≥1A)가 별도 3.3V 레일을 공급합니다.

D0/D1(하드웨어 UART)은 USB 시리얼 업로드/디버깅 전용으로 비워두고, RS485 통신은 D5/D6에 SoftwareSerial로 배정했습니다. D10과 A3 계열의 일부 핀은 Sheet 5를 디코더 방식으로 전환하며 여유 핀으로 남았습니다(D10은 현재 미사용).

## 핀맵 전체

핀 | 넷 이름 | 방향 | 용도 / 연결 시트
D0 | (미사용) | - | 예비 — 하드웨어 UART RX, USB 디버깅 전용으로 비움
D1 | (미사용) | - | 예비 — 하드웨어 UART TX, USB 디버깅 전용으로 비움
D2 | DEC_A | OUT | Sheet5 — 74LVC138A 주소비트 A0
D3 | DEC_B | OUT | Sheet5 — 74LVC138A 주소비트 A1
D4 | DEC_C | OUT | Sheet5 — 74LVC138A 주소비트 A2
D5 | 485_RX | IN | Sheet3 — SoftwareSerial RX (U3 RO 경유)
D6 | 485_TX | OUT | Sheet3 — SoftwareSerial TX (U3 DI 경유)
D7 | BUZZ | OUT | Sheet6 — 부저(BZ1) 직접 구동
D8 | BANK | OUT | Sheet5 — 74LVC138A 뱅크선택(U6/U7 상호배타 전환)
D9 | RST | OUT | Sheet5 — MFRC522 공통 RST (U8C 경유)
D10 | (미사용) | - | 예비 — Sheet5 디코더 전환으로 해제된 여유 핀
D11 | MOSI | OUT | Sheet5 — SPI MOSI (U8B 경유)
D12 | MISO_5V | IN | Sheet5 — SPI MISO (U9 출력)
D13 | SCK | OUT | Sheet5 — SPI SCK (U8A 경유)
A0 | OPEN_BTN | IN | Sheet2 — 로컬 개방 버튼(INPUT_PULLUP)
A1 | OPEN_CTL | OUT | Sheet2 — 도어락 구동 제어(Q2 게이트)
A2 | LOCK_STATE | IN | Sheet2 — 도어 상태 감지(INPUT_PULLUP)
A3 | DEV_ID | IN | Sheet6 — 74HC165 Q7 시리얼 출력(장치 ID 8비트)
A4 | DEV_PL | OUT | Sheet6 — 74HC165 PL(SH/LD, 래치)
A5 | DEV_CP | OUT | Sheet6 — 74HC165 CP(클럭)
RESET | arduino_rst (S_Reset) | IN | Sheet4 — Q4 소프트리셋 출력(워치독 1단계)
5V | 5V_RAW | IN | Sheet1 — 유일한 전원 입력
VIN | (미사용) | - | 미연결 — 온보드 리니어 레귤레이터 발열 회피
3V3 | (미사용) | - | 미연결 — 온보드 출력 용량 부족(≈50mA), Sheet1 U2로 대체
GND | GND | - | 공통 그라운드

# 9. 통합 BOM (전체 시트, 지정자순)

아래는 시트 1~6 및 MCU 루트 시트에서 사용된 전체 부품을 지정자(Reference Designator) 기준으로 정렬해 하나로 통합한 표입니다. 각 시트별 상세 BOM은 해당 섹션을 참고하십시오.

지정자 | 부품 | 정격/값 | 비고 | 출처
A1 | Arduino 보드 | Arduino_UNO_R3 | 소켓 마운트, VIN/3V3 미사용 | Root
BZ1 | 피에조 부저 | Buzzer | D7 직접구동 | S6
C1 | 전해커패시터 | 100uF/25V | 12V 벌크 커패시턴스 | S1
C2 | 세라믹커패시터 | 0.1uF | 고주파 디커플링 | S1
C3 | 세라믹커패시터 | 10uF | U1 입력 디커플링 | S1
C4 | 세라믹커패시터 | 22uF | U1 출력(5V_RAW) 디커플링 | S1
C5 | 세라믹커패시터 | 10uF | U2 입력 디커플링 | S1
C6 | 세라믹커패시터 | 22uF | U2 출력(3V3_RAW) 디커플링 | S1
C7 | 세라믹커패시터 | 0.1uF | U3(RS485) VCC 디커플링 | S3
C9 | 세라믹커패시터 | 0.1uF | U4 활동감지 피크홀드 | S4
C10 | 세라믹커패시터 | 0.1uF | U4 VCC 디커플링 | S4
C11 | 세라믹커패시터 | 100nF | U7측 3V3_RAW 디커플링 | S5
C12 | 세라믹커패시터 | 100nF | U6측 3V3_RAW 디커플링 | S5
C13 | 세라믹커패시터 | 100nF | U8 VCC 디커플링 | S5
C14 | 세라믹커패시터 | 100nF | U9 VCC 디커플링 | S5
D1 | 쇼트키 다이오드 | SS54 (5A/40V) | 역전압 보호 | S1
D2 | 정류 다이오드 | 1N4007 | 도어락 플라이백 보호 | S2
D3 | 양방향 TVS 다이오드 | SMAJ14CA | 서지 보호 | S1
D4 | 소신호 다이오드 | 1N4148 | 485_RX 활동감지 피크검출 | S4
F1 | 폴리퓨즈 | 2A | 과전류 보호 | S1
J1 | DC 배럴잭 | Barrel_Jack | 12V_IN 입력 | S1
J2 | 4핀 소켓 커넥터 | Conn_01x04_Socket | DoorLock 커넥터 | S2
J3 | 2핀 소켓 커넥터 | Conn_01x02_Socket | Push Btn 커넥터 | S2
J4 | 2핀 소켓 커넥터 | Conn_01x02_Socket | to Server RS485 | S3
J_MFC_1~10 | 8핀 소켓 커넥터 ×10 | Conn_01x08_Socket | MFRC522 리더 커넥터 | S5
Q1 | P채널 MOSFET | PMOSFET | 고전위측 로드스위치(콜드리셋) | S1
Q2 | N채널 로직레벨 MOSFET | IRLZ44N | 도어락 구동 | S2
Q3 | NPN 트랜지스터 | 2N3904 | H_Reset 반전 구동 | S1
Q4 | NPN 트랜지스터 | 2N3904 | 소프트리셋 구동 | S4
R1 | 저항 | 10K | Q1 게이트 풀업 | S1
R2 | 저항 | 10K | Q3 베이스 전류 제한 | S1
R3 | 저항 | 10K | Q2 게이트 풀다운 | S2
R4 | 저항 | 220Ω | Q2 게이트 전류 제한 | S2
R5 | 저항 | 22Ω | U3 RO 직렬 | S3
R6 | 저항 | 22Ω | U3 DI 직렬 | S3
R7 | 저항 | 10K | B라인 풀다운 바이어스 | S3
R8 | 저항 | 120Ω | 버스 종단 | S3
R9 | 저항 | 10K | A라인 풀업 바이어스 | S3
R10 | 저항 | 1M | C9 방전(시정수) | S4
R11 | 저항 | 10K | Q4 베이스 저항 | S4
R12 | 저항 | 220Ω | BZ1 전류제한 | S6
R13 | 저항 | 33Ω | SCK_3V3 직렬 | S5
R14~R21 | 저항 ×8 | 10K | U5 D0~D7 풀업 | S6
R22 | 저항 | 33Ω | MOSI_3V3 직렬 | S5
R23 | 저항 | 33Ω | RST_3V3 직렬 | S5
R25~R32 | 저항 ×8 | 33Ω | SS_1~8 직렬 | S5
R33, R34 | 저항 ×2 | 33Ω | SS_9~10 직렬 | S5
SW1 | 전압 선택 스위치 | SW_SPDT | 12V_LOCK↔5V_RAW 선택 | S2
SW2 | DIP 스위치(1P) | SW_DIP_x01 | 종단저항 유효화 | S3
SW3 | 스위치(1P) | VCC485BiasSW | A라인 바이어스 인에이블 | S3
SW4 | DIP 스위치(1P) | SW_DIP_x01 | B라인 바이어스 인에이블 | S3
SW5, SW6 | DIP 스위치 ×2 | SW_DIP_x04 | 장치 ID 8비트 | S6
U1 | DC-DC 벅컨버터 | MP2307DN | 12V→5V | S1
U2 | 3.3V LDO 레귤레이터 | AMS1117-3.3 | 5V_RAW→3V3_RAW | S1
U3 | RS485 트랜시버 | MAX13487E | AutoDirection | S3
U4 | 보조 감시 MCU | ATtiny13A-P (DIP-8) | 소켓 실장, 별도 프로그래밍 | S4
U5 | 8bit PISO 시프트레지스터 | 74HC165 | 장치 ID 읽기 | S6
U6, U7 | 3:8 라인 디코더 ×2 | 74LVC138A | SS 핀 절감(10→4핀) | S5
U8 | 쿼드 트라이스테이트 버퍼 | 74LVC125A | SCK/MOSI/RST 레벨시프트 | S5
U9 | 단일 트라이스테이트 버퍼 | 74AHCT1G125 | MISO 레벨시프트 | S5

범례 — S1: 전원부 / S2: 도어락 구동부 / S3: RS485 통신부 / S4: 리셋·워치독 / S5: RFID 리더부 / S6: 장치ID·부저 / Root: MCU 루트 시트

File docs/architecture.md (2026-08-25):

# NFC Smart Vault — 협업 가능한 구조로 재설계 제안서

> 목적: 기존 1인 개발 코드(`data.zip`, `.ino`)는 **참고용**입니다. 여기서는 그 코드를 고치는 게 아니라,
> 그 안에 들어있는 "검증된 로직"만 뽑아내고, 확장·협업이 가능한 형태로 **새로 설계**합니다.

---

## 1. 기존 코드에서 확인된 사실 (설계 근거)

새로 설계하기 전에, 기존 코드가 실제로 어떻게 동작하고 있었는지부터 정리했습니다. 이건 "무엇을 유지해야 하는 핵심 로직"과 "무엇을 반드시 버려야 하는 구조"를 가르는 기준이 됩니다.

### 1-1. 하드웨어/펌웨어 (`ver1_2_1_..._MCU.ino`)
- Arduino 기반 MCU 1개가 **MFRC522 RFID 리더 최대 10개**를 SPI SS핀 멀티플렉싱으로 제어
- 게이트웨이마다 `myName`(g1, g2...) 이라는 고유 ID를 가지고, `SoftwareSerial`로 **RS485 데이지체인**을 통해 상위 시스템(Python)과 통신
- 통신 프로토콜이 `!g1CCCO`, `:ID:...:RD:...:END:` 같은 **직접 정의한 텍스트 프로토콜** — 구분자 파싱을 직접 처리, 체크섬/재전송 없음
- 워치독 타이머(`wdt`), 도어 상태 핀, 부저 멜로디, 리더 초기화 로직까지 — **현장에서 실제로 튜닝된 로직**이라 이 부분의 타이밍/상태값은 그대로 자산으로 유지해야 함

### 1-2. 게이트웨이 브리지 (`serial-org-loop.py` 등)
- 초 단위(`readTimeList`)로 폴링하며 시리얼 포트에 명령 전송 → 응답을 파싱해서 **로컬 텍스트 파일**(`log/*.txt`, `secData/company*/room*/*.txt`)에 기록
- 파일 하나(`sum.txt`)가 **1GB 이상**까지 누적되는 구조 — DB가 아니라 파일 append 방식
- 스크립트 버전이 `15Data30.py`, `15Data30 extend.py`, `...backup.py`, `...Debug.py` 등 **파일명으로 버전 관리** 중 (git 미사용 추정)

### 1-3. 백엔드 (`server.js`, Express + MySQL)
- **DB 접속 정보(호스트/계정/비밀번호)가 소스코드에 평문으로 하드코딩**되어 있고, 주석 처리된 중복 버전도 함께 커밋되어 있음 → 이건 재설계 여부와 무관하게 **지금 바로 로테이션(비밀번호 변경) 권장**
- SQL 쿼리를 문자열 concat으로 직접 조립(`"UPDATE ... WHERE (IDsequence = '" + idxcode + "')"`) → SQL Injection에 열려있음
- `cors({ origin: '*', credentials: true })` — 이 조합은 스펙상 브라우저에서 정상 동작하지 않거나 보안상 위험한 설정
- 라우트 핸들러 하나가 여러 단계 조건 분기(`Searchoption1===1 && Searchoption2===6` 등)를 안에서 다 처리 — 비즈니스 로직/DB 접근/응답 포맷팅이 분리되어 있지 않음

### 1-4. 프론트엔드 (React, CRA + react-app-rewired)
- 라우팅 구조 자체(`/regi/newUser`, `/regi/newDetected`, `/regi/SetupTimeTable` 등)는 **등록 플로우가 명확하게 나뉘어 있어 재사용 가치가 있음**
- 다만 `Menu.jsx`/`Menucopy.jsx`, `MainFrame.jsx`/`MainFrame-back.jsx`, `TableCreate.jsx`/`TableCreate1.jsx`처럼 **"copy/back" 파일이 진짜 버전과 나란히 존재** — 협업 시 "어느 게 최신인지" 판단 불가능한 상태

**결론**: 로직(RFID 멀티리더 제어, RS485 주소체계, 등록 플로우, 도어 상태 판단)은 실전 검증된 자산이지만, **구조(버전관리, 보안, 계층 분리, 데이터 저장방식)는 처음부터 다시 짜는 게 맞습니다.** 사장님 판단이 정확합니다.

---

## 2. 새 아키텍처 개요

부대 1개 = 내무반 10~수십 개 = Vault(보관함) 10~수십 대 = RFID 리더 최대 수백 개, 이걸 **부대 안의 중앙관리서버 1대**가 모니터링해야 하고, **인터넷이 없는 폐쇄망**이라는 전제가 붙었습니다. 이 조건이 아키텍처의 핵심 제약이라 다이어그램을 계층형으로 다시 그렸습니다.

```
[내무반 1]  Vault(MCU+RFID×10) ─┐
[내무반 2]  Vault(MCU+RFID×10) ─┤  RS485 buses
[내무반 3]  Vault(MCU+RFID×10) ─┤  (건물/층별로 분리)
   ...                          │
[내무반 N]  Vault(MCU+RFID×10) ─┘
                │
                ▼
     ┌─────────────────────┐
     │  건물별 Concentrator  │  ← RS485 세그먼트 종단, Python 브리지 상주
     │  (미니PC/산업용 게이트웨이)│    로컬 SQLite 버퍼(오프라인 큐)
     └──────────┬───────────┘
                │ 부대 내부망(유선 LAN, 인터넷 미경유)
                ▼
     ┌─────────────────────┐
     │  중앙 관리서버 (부대 내)│  ← 인터넷 연결 없음, 전부 자체 호스팅
     │  API Server + DB      │
     │  + 관리자 대시보드      │
     └─────────────────────┘
```

핵심 설계 포인트 4가지:
1. **RS485 세그먼트 분할**: RS485 한 버스에 물릴 수 있는 노드 수(표준 트랜시버 기준 32개)와 배선 길이 한계 때문에, 내무반이 많은 부대는 **건물/층 단위로 RS485 버스를 나누고**, 그 버스마다 Concentrator(로컬 브리지 PC) 1대를 둡니다. 지금처럼 브리지 하나가 시리얼 포트 하나만 보는 구조로는 내무반 수십 개를 감당할 수 없습니다.
2. **오프라인 내성**: 폐쇄망이라도 부대 내부 LAN 자체가 순간적으로 끊길 수 있습니다. Concentrator는 중앙서버와 연결이 끊겨도 로컬(SQLite)에 이벤트를 쌓아두고, 재연결되면 밀린 데이터를 동기화합니다. **잠금/해제 판단 자체는 MCU/Concentrator 레벨에서 독립적으로 동작**해야 하고, 중앙서버는 "기록·모니터링·정책 배포" 역할로 한정합니다 — 중앙서버가 죽어도 현장 보관함은 정상 동작해야 합니다.
3. **파일 기반 로그 → DB 직접 적재**: Concentrator가 텍스트 파일에 append 하는 대신, 구조화된 이벤트를 중앙 API로 바로 전송(또는 오프라인 시 로컬 큐 후 재전송)
4. **비밀정보 분리 + 완전 자체 호스팅**: 인터넷 의존 서비스(클라우드 DB, 외부 NTP, 외부 시크릿 매니저 등) 전부 제거하고 부대 내부에서 자체적으로 돌아가는 구성만 사용

---

## 3. 다중 사이트 · 폐쇄망 환경 대응 설계

### 3-1. 계층적 ID 체계로 전환

지금은 `myName`이 `g1`, `g2`처럼 평면적인 이름입니다. 부대 하나에 내무반 수십 개, 나중에 부대 여러 곳으로 확장되는 걸 감안하면 처음부터 계층 ID를 써야 나중에 안 꼬입니다.

```
{부대코드}-{건물코드}-{내무반코드}-{게이트웨이순번}
예: 1CORPS-B3-R204-G1
```

- 이 ID를 MCU 펌웨어의 `myName` 자리에 그대로 넣고, DB의 `gateways` 테이블 기본키로도 사용
- 나중에 부대가 여러 곳으로 늘어나도(사업계획서상 확장 시나리오) 이 체계 그대로 확장 가능

### 3-2. RS485 세그먼트 설계 기준

| 항목 | 기준 | 비고 |
|---|---|---|
| 세그먼트당 최대 노드 수 | 표준 트랜시버 기준 32개, 여유 두고 20개 이하로 운영 권장 | 내무반 20개 이상인 건물은 세그먼트 2개 이상으로 분리 |
| 배선 길이 | 한 세그먼트 내 배선이 길어지면 종단저항·통신 안정성 확인 필요 | 건물 단위 분리가 현실적 |
| Concentrator 1대당 담당 범위 | 세그먼트 1~2개 (내무반 약 15~30개) | Concentrator는 저사양 미니PC/산업용 PC로 충분 |

부대 규모(내무반 10개 ~ 수십 개)를 감안하면, **건물별로 Concentrator를 1대씩 두고, 중앙서버는 Concentrator들의 접속만 받는 구조**가 가장 현실적입니다. 내무반 10개짜리 소규모 부대는 Concentrator와 중앙서버를 물리적으로 한 대(PC 한 대)에 합쳐도 됩니다 — 규모에 따라 스케일업/스케일다운이 가능하게 설계합니다.

### 3-3. 폐쇄망 특화 고려사항

| 항목 | 일반 인터넷 환경 가정 | 폐쇄망(부대) 대응 |
|---|---|---|
| 시간 동기화(NTP) | 공용 NTP 서버 | 중앙서버를 부대 내부 NTP 소스로 지정, 모든 Concentrator/클라이언트가 이걸 참조 |
| 소프트웨어 업데이트 | `git pull`, `npm install`, OTA | 인터넷 미경유 — 검증된 패키지를 USB 등 물리 매체로 반입하는 내부 배포 절차 필요 (군 보안 규정에 따른 반입 승인 절차 포함) |
| DB/시크릿 관리 | 클라우드 매니지드 DB, AWS Secrets Manager 등 | 전부 온프레미스: PostgreSQL/MySQL 자체 호스팅, `.env` 또는 로컬 Vault(HashiCorp Vault 자체 구축)로 제한 |
| 원격 장애 대응 | 원격 로그 수집(Sentry 등 외부 SaaS) | 로컬 로그 수집(자체 ELK 또는 파일 로그 + 로테이션)만 사용, 외부 전송 없음 |
| 도메인/인증서 | 공인 도메인 + Let's Encrypt | 내부 CA 발급 인증서 또는 사설 IP 기반, 공인 인증서 발급 불가 전제 |

### 3-4. 감사(Audit) 로그 강화

민간 상용 사물함과 달리, **군부대 스마트폰 보관함은 "누가 언제 폰을 넣고 뺐는지"가 지휘/보안 감사 목적**과 직결됩니다. 데이터 계층 설계 시 아래를 기본으로 포함합니다.

- `rfid_events` 테이블: (부대ID, 내무반ID, 게이트웨이ID, 리더인덱스, RFID UID, 이벤트유형(입고/출고), 타임스탬프) — **수정·삭제 불가(append-only)**, 삭제는 보존기간 정책에 따른 별도 아카이빙만 허용
- 도어 개폐 이벤트도 별도 테이블로 기록 (누가 강제로 열었는지 등 이상 상황 추적)
- 관리자 계정의 조회/설정 변경 이력도 감사로그 테이블에 별도 기록

### 3-5. 중앙서버가 다중 Concentrator를 수용하는 방식

부대 하나에서 Concentrator가 최대 수 대~십수 대가 동시에 중앙서버로 이벤트를 보냅니다. 인터넷 트래픽이 아니라 폐쇄망 내부 트래픽이라 규모 자체는 크지 않지만, 설계는 아래처럼 갑니다.

- 중앙서버는 Concentrator별 **persistent 연결(WebSocket 또는 장기 TCP)** 을 유지해 실시간성 확보 + 연결 끊김 자체를 장애 감지 신호로 활용(대시보드에 "내무반 204 연결 끊김" 알림)
- 이벤트 수신은 큐(내부 메시지 큐, 예: Redis Streams — 이것도 로컬 설치) 뒤에서 비동기로 DB에 적재해 순간 부하 흡수
- DB는 부대/건물/내무반 기준으로 인덱스 설계, 대시보드 조회는 "부대 전체 → 건물별 → 내무반별" 드릴다운 구조로 쿼리 최적화

---

## 4. 레포지토리 구조 제안 (모노레포)

```
smartvault/
├── firmware/                 # 하드웨어 펌웨어
│   ├── gateway-mcu/           # 현재 .ino 로직 정리 (게이트웨이별 빌드)
│   │   ├── src/
│   │   │   ├── rfid_multiplexer.cpp
│   │   │   ├── lock_controller.cpp
│   │   │   ├── protocol.cpp     # 통신 프로토콜만 분리
│   │   │   └── main.cpp
│   │   ├── include/pitches.h
│   │   └── platformio.ini     # Arduino IDE 대신 PlatformIO 권장 (버전관리·CI 용이)
│   └── docs/protocol-spec.md  # 프로토콜 명세서 (아래 4장)
│
├── gateway-bridge/            # 시리얼 ↔ 서버 브리지 (Python)
│   ├── bridge/
│   │   ├── serial_client.py
│   │   ├── protocol_parser.py # !g1CCCO 같은 텍스트 프로토콜 파싱 전담
│   │   ├── event_publisher.py # DB/API로 이벤트 전송
│   │   └── config.py
│   ├── tests/
│   └── requirements.txt
│
├── backend/                   # API 서버
│   ├── src/
│   │   ├── routes/
│   │   ├── services/           # 비즈니스 로직 (server.js에 섞여있던 부분)
│   │   ├── repositories/       # DB 쿼리 전담 (파라미터 바인딩 강제)
│   │   ├── middlewares/auth.js
│   │   └── app.js
│   ├── migrations/             # DB 스키마 버전 관리
│   ├── .env.example
│   └── package.json
│
├── frontend/                  # 관리자 웹 대시보드
│   ├── src/
│   │   ├── pages/               # regi/newUser 등 기존 라우팅 구조 재사용
│   │   ├── components/
│   │   ├── api/                 # fetch 로직 한 곳에 모으기
│   │   └── App.jsx
│   └── package.json
│
├── docs/
│   ├── architecture.md
│   ├── onboarding.md          # 신규 팀원 온보딩 가이드
│   └── api-spec.md            # (Swagger/OpenAPI 권장)
│
├── .github/workflows/         # CI (lint, test, build)
├── docker-compose.yml         # 로컬 개발환경 통일 (backend+db+bridge 한 번에)
└── README.md
```

**왜 모노레포인가**: 사업계획서 기준으로 CTO 1명 + 개발자 1명(예정) 규모입니다. 이 정도 팀 크기에서는 레포 여러 개로 쪼개면 오히려 PR/버전 동기화 비용이 커집니다. 나중에 팀이 커지면 그때 `firmware`, `backend`를 별도 레포로 분리해도 늦지 않습니다.

---

## 5. 통신 프로토콜 재설계

현재 프로토콜(`!g1CCCO`, `:ID:...:RD:...:END:`)은 동작은 하지만, 팀원이 늘면 "이 5번째 글자가 뭘 의미하는지" 코드를 읽어야만 압니다. 재설계 시:

1. **명세서를 코드보다 먼저 작성** (`firmware/docs/protocol-spec.md`)
   - 명령어 표: `!{게이트웨이ID}{잠금상태}{리셋}{리더동작}{기타}` 형태로 필드별 의미/허용값을 표로 정리
   - 응답 형태(`:ID:`, `:RD:`, `:END:` 등 delimiter)도 동일하게 표로 정리
2. **경량 프레이밍 유지, 체크섬만 추가**: RS485 대역폭이 크지 않으므로 JSON 전면 전환보다는, 기존 텍스트 프로토콜에 **XOR 체크섬 1바이트**만 추가해 전송 오류를 잡아내는 정도가 현실적입니다 (완전 JSON은 저사양 MCU에 부담)
3. **Python 브리지에서 파싱 직후 구조화**: 브리지 안에서 파싱한 결과는 즉시 아래 형태의 이벤트로 변환해서 API로 전달

```json
{
  "gateway_id": "g1",
  "event_type": "rfid_detected",
  "reader_index": 3,
  "rfid_uid": "3A9F1C22",
  "door_state": "closed",
  "ts": "2026-08-24T10:15:03Z"
}
```

이렇게 하면 백엔드/DB/프론트는 저수준 텍스트 프로토콜을 몰라도 되고, 펌웨어 담당자만 그 명세서를 알면 됩니다 — **역할 분리가 곧 협업 가능 구조**입니다.

---

## 6. 데이터 계층 재설계

| 현재 | 문제 | 제안 |
|---|---|---|
| `log/*.txt`, `secData/.../total.txt` (append, 최대 1GB+) | 파일 잠금 경쟁, 조회 불가능한 raw text, 백업/복구 어려움 | RDB의 `events`, `rfid_reads`, `door_states` 테이블로 즉시 적재 |
| `server.js` 안에 SQL 문자열 concat | SQL Injection | ORM 또는 파라미터 바인딩 쿼리(`?` 플레이스홀더) 강제, repository 계층에서만 SQL 작성 |
| 코드에 평문 비밀번호 | 유출 시 DB 전체 노출 | `.env` + 배포 환경에서는 시크릿 매니저(AWS Secrets Manager, 또는 최소 `.env` + `.gitignore`) |
| 세션/인증 로직이 라우트 안에 산재 | 재사용 불가 | `middlewares/auth.js`로 통합, JWT 또는 세션 방식 택1 |

**즉시 조치 권장(재설계와 별개로 지금 해야 할 것)**: 기존 서버가 아직 살아있다면 DB 비밀번호부터 교체하세요. 코드가 zip으로 공유된 이상 이미 노출된 것으로 간주하는 게 안전합니다.

인원(군인)-RFID 매핑, 도어 개폐 정책, 판정 이벤트까지 포함한 상세 스키마는 [data-model-personnel-door-control.md](./data-model-personnel-door-control.md) 참고.

---

## 7. 협업 프로세스 (개발자 합류 대비)

사업계획서에 소프트웨어 개발자 합류 예정(’26.6)이 명시돼 있으니, 그 시점 기준으로 준비하면 됩니다.

1. **Git 브랜치 전략**: `main`(배포) / `develop`(통합) / `feature/*` — 팀 2~3명 규모에는 GitHub Flow(단순히 `main` + `feature/*` + PR)가 오히려 더 적합할 수 있습니다
2. **"copy/back" 파일 금지**: 버전은 git 커밋/브랜치로만 관리 — `MainFrame-back.jsx` 같은 파일이 다시 생기지 않도록 `.gitignore` + PR 리뷰 규칙에 명시
3. **환경변수 템플릿**: `.env.example`을 레포에 커밋하고 실제 `.env`는 절대 커밋 금지
4. **온보딩 문서**: `docs/onboarding.md`에 "로컬에서 백엔드+DB+브리지 띄우는 법"을 `docker-compose up` 한 줄로 끝나게 정리 — 신규 개발자가 첫날 바로 개발 가능하게
5. **API 명세**: Swagger/OpenAPI로 프론트-백엔드 계약을 문서화하면, 프론트 개발자가 백엔드 코드를 안 봐도 작업 가능

---

## 8. 단계별 로드맵 제안

| 단계 | 내용 |
|---|---|
| Phase 0 | 기존 서버 DB 비밀번호 교체, 레포 구조 세팅, `.env` 분리 |
| Phase 1 | 프로토콜 명세서 작성(체크섬 포함) → 펌웨어 리팩토링(로직은 유지, 파일 구조만 정리), 계층형 ID 체계 확정 |
| Phase 2 | Concentrator(구 게이트웨이 브리지) 재작성 — 로컬 큐잉/오프라인 재동기화 포함, RS485 다중 세그먼트 대응 |
| Phase 3 | 백엔드 API 재작성 (레이어 분리, SQL 파라미터 바인딩, 인증 미들웨어, 다중 Concentrator 수용 구조) |
| Phase 4 | 프론트엔드 정리 (부대→건물→내무반 드릴다운 대시보드, 기존 라우팅 구조 재사용) |
| Phase 5 | 소규모 시범 배치(내무반 1~2개)로 실증 → 문제점 보완 |
| Phase 6 | 폐쇄망 배포 절차 확정(오프라인 설치 매뉴얼, 내부 CA/인증서, 로컬 NTP) 및 CI/CD, 온보딩 문서 정비 → 팀원 합류·부대 확대 배치 준비 완료 |

---

## 다음으로 필요하신 것

- **Phase 1 (프로토콜 명세서 + 펌웨어 구조)** 부터 실제 코드로 시작해드릴까요?
- 아니면 **Phase 3 (백엔드 API 스켈레톤)** 을 Express/TypeScript로 먼저 세팅해드릴까요?
- DB 스키마(테이블 설계)부터 확정하고 싶으시면 그것도 바로 진행 가능합니다.

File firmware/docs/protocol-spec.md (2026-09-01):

# 게이트웨이 통신 프로토콜 명세

`vault-gateway/rs485_link.cpp`가 구현체다. 이 문서와 코드가 어긋나면 코드를 기준으로
문서를 고친다(문서 먼저 고치고 코드를 나중에 맞추는 반대 순서 금지 — 실물 보드가
이미 이 스펙으로 동작 중일 수 있으므로).

RS485 보레이트: **19200bps** (`gateway-bridge/.env.example`의 `BAUD_RATE`와 반드시 일치).

## 버스 충돌 최소화 원칙 (2026-09-02 확정)

RS485는 반이중 멀티드롭이라, 여러 게이트웨이가 동시에 선로에 뭔가를 실으면 프레임끼리
겹쳐서 전부 깨진다. 이 프로토콜은 그걸 막으려고 명령을 두 종류로 나눈다.

- **응답 불필요(fire-and-forget)**: LOCK(도어락 정책), RESET(전체/개별 재부팅류). 집중장치가
  보내기만 하면 끝 — 게이트웨이는 아무것도 돌려보내지 않는다. 이 종류는 **브로드캐스트해도
  안전하다**(아무도 응답 안 하니 충돌할 게 없음).
- **응답 필요**: READEROP='R'(리더 스캔). 이건 **반드시 게이트웨이 하나씩, 순차적으로만**
  보내야 한다 — 브로드캐스트로 여러 게이트웨이에 동시에 물어보면 전부 동시에 응답을
  쏟아내서 충돌한다. 펌웨어 쪽에서도 마지막 방어선을 둬서, `READEROP='R'`인데 대상이
  브로드캐스트면 **응답 자체를 만들지 않고 무시**한다(`rs485_link.cpp`의
  `if (readerOp == 'R' && isMine)` — 집중장치 구현 실수로 브로드캐스트+R을 보내도 최소한
  버스가 응답 폭주로 마비되진 않게).
- **게이트웨이는 명령 없이 스스로 아무것도 전송하지 않는다.** 예전엔 도어 상태를 2초마다
  자동으로 하트비트로 쏘고 있었는데, 이게 실제 버그였다 — 버스에 물린 여러 게이트웨이의
  타이머가 서로 안 맞춰져 있어서, 언젠가는 두 게이트웨이의 2초 주기가 겹쳐서 충돌할 수
  있었다(2026-09-02 제거). 지금은 상태(도어 잠금/열림)도 **READEROP='R' 응답 맨 앞에
  한 프레임 얹어서만** 나간다 — 별도 명령이나 자동 타이머 없이, "RFID 데이터를 모을 때
  상태 정보도 한꺼번에 전달"하는 구조.

## 게이트웨이 ID 구조 — 그룹 + DIP주소, 최종 이름은 서버가 부여

게이트웨이가 RS485에서 자기 자신을 밝히는 ID는 **4글자**: `{GATEWAY_GROUP_ID(2글자)}{DIP주소(2자리 HEX)}`.

- **DIP주소**: 74HC165로 읽는 8비트. 같은 RS485 버스(세그먼트) 안에서만 유일 — 버스 레벨
  주소 지정에 필요한 만큼만 담당.
- **GATEWAY_GROUP_ID**: `firmware/vault-gateway/gateway_identity.h`에 정의된 컴파일타임
  상수(설치자가 하드웨어 배치/펌웨어 버전마다 직접 편집 후 빌드). DIP만으로는 "이게 어떤
  하드웨어/펌웨어 배치인지" 알 수 없어서, 서로 다른 배치를 구분하기 위해 붙였다.
- 이 4글자는 **DB의 최종 `gateway_id`(예: `1CORPS-B3-R204-G1`)가 아니다.** 어디까지나
  "이 물리 장치를 가리키는 원시 식별자"다. 사람이 읽을 수 있는 최종 이름은 **서버의
  게이트웨이 등록 화면(`GatewayListPage.jsx`)에서 관리자가 부여**한다 — 지금 이미 있는
  `detected_gateways`(미등록 장치 자동 로그) → 관리자가 방과 매칭 → `gateways`에 정식
  등록되는 흐름을 그대로 재사용한다(새 테이블/화면 필요 없음). 등록되고 나면 **집중장치가
  이 매핑(4글자 원시ID ↔ 최종 gateway_id)을 캐시해서 관리** — 이후 서버로 보고할 땐 최종
  이름으로 보낸다.
- `"FF"`는 브로드캐스트 예약값이라 GATEWAY_GROUP_ID로 쓰면 안 된다 — `gateway_identity.h`의
  static_assert가 이 값이면 컴파일 자체를 막는다(대문자 "FF"만 검사).

## RFID는 "이벤트"가 아니라 "지금 상태 조회"다

스마트폰이 슬롯에 몇 시간씩 계속 거치돼 있는 걸 실시간으로 파악해야 하는 시스템이라,
"새로 인식된 순간에만 보고"하는 방식은 안 맞는다(거치돼 있는 카드는 MFRC522의
`PICC_IsNewCardPresent()`가 REQA 기반이라 한 번 읽고 나면 HALT 상태가 돼서 계속
거치돼 있어도, 심지어 빼도 다시 안 잡힌다). 그래서:

- 게이트웨이는 리더를 스스로 훑지 않는다 — **집중장치가 `READEROP='R'`로 명시적으로
  물어볼 때만** 리더를 재초기화해서 다시 감지 가능하게 만든 뒤 응답한다.
- 응답은 "카드가 새로 인식됨" 이벤트가 아니라 "지금 이 순간 이 리더에 뭐가 있는지"
  현재 상태(`PRESENT` 0/1 + UID)다.
- **check_in/check_out(입고/출고) 전환 판단은 게이트웨이가 하지 않는다.** 게이트웨이는
  매번 있는 그대로의 현재 상태만 보내고, 이전 상태와 비교해서 "새로 놓임"/"빠짐" 전환을
  만드는 건 **집중장치(`gateway-bridge`)가 기본으로 담당**하며, 그 결과를 서버 이벤트
  관리(`backend/src/services/ingestService.js`)로 넘겨서 확장 가능한 구조로 간다 —
  즉 집중장치가 리더별 마지막 상태를 들고 있다가, 새 응답이 오면 diff해서
  `check_in`/`check_out`/`unknown`을 만들어 `POST /api/ingest/events`로 보낸다.

## 명령 (집중장치 → 게이트웨이)

고정 11바이트 + 개행(`\n`):

```
!{ID}{LOCK}{RESET}{READEROP}{READERIDX}{CHECKSUM}
```

| 위치 | 이름 | 길이 | 허용값 | 의미 |
|---|---|---|---|---|
| 0 | 시작 | 1 | `!` | 프레임 시작 |
| 1-4 | ID | 4 | `{GATEWAY_GROUP_ID 2글자}{DIP 2자리 HEX}` | 대상 게이트웨이(위 "게이트웨이 ID 구조" 참고). `FFFF`=전체 브로드캐스트 |
| 5 | LOCK | 1 | `O`/`C` | Open/Close — 서버가 판단한 "지금 잠금/열림" 정책 상태. 게이트웨이는 이 값을 그대로 캐시했다가 OPEN_BTN 입력과 대조한다(주간 스케줄 자체는 서버가 계산, 게이트웨이는 안 들고 있음) |
| 6 | RESET | 1 | `A`/`I` | 전체/개별 재부팅류 — **TODO: 아직 firmware에서 미구현**, 파싱만 하고 무시 |
| 7 | READEROP | 1 | `R`/`A` | `R`=지금 리더 스캔해서 상태 보고, `A`=응답 불필요(락 상태만 캐시) |
| 8 | READERIDX | 1 | `0`-`9`/`A` | READEROP='R'일 때만 의미 있음 — `0`-`9`면 그 리더 하나만, `A`면 10개 전부 순서대로 스캔+응답 |
| 9-10 | CHECKSUM | 2 | HEX | `!`부터 READERIDX까지(인덱스 0~8, 9바이트) XOR |

체크섬이 안 맞거나 프레임 길이가 11바이트가 아니면 게이트웨이는 조용히 버린다(재전송은
집중장치 책임 — 응답 없음을 재전송 트리거로 씀).

## 응답 (게이트웨이 → 집중장치)

**응답은 오직 `READEROP='R'`이고 자기 앞으로(브로드캐스트 아님) 온 명령에 대해서만
나간다.** 그 외 상황(LOCK/RESET만 온 경우, 자기 프레임이 아닌 경우, 체크섬 불일치)엔
아무것도 전송하지 않는다 — 위 "버스 충돌 최소화 원칙" 참고.

한 번의 `R` 명령에 대해 응답은 항상 이 순서로 나간다:

1. **상태 프레임 1개** (그 시점의 실제 도어 상태 + 게이트웨이가 인식 중인 정책)
   ```
   :ID:{4글자}:LOCK:{O|C}:POLICY:{O|C}:END:{CHECKSUM 2 hex}
   ```
   - `LOCK`: **LOCK_STATE 핀으로 실측한 실제 도어 상태**
   - `POLICY`: 서버가 마지막으로 내려준 LOCK 명령을 게이트웨이가 캐시해서 "지금 이렇게
     적용해야 한다"고 인식하고 있는 값(`door_lock.cpp`의 `doorLock_isCommandedUnlocked`)
   - 이 둘은 다를 수 있다 — 예: 정책은 열림 허용(`POLICY=O`)인데 아직 아무도 버튼을 안
     눌러서 실제로는 잠긴 채(`LOCK=C`)인 경우. 집중장치가 "게이트웨이가 지금 뭘 인식하고
     있는지"와 "실제로 어떤 상태인지"를 구분해서 볼 수 있게 둘 다 실었다(2026-09-02).
2. **리더 상태 프레임 1개 또는 10개** (READERIDX가 `0`-`9`면 1개, `A`면 리더 0부터 9까지
   순서대로 10개)
   ```
   :ID:{4글자}:RD:{리더idx 1 hex}:PRESENT:{0|1}:UID:{UID hex, present=0이면 빈 문자열}:END:{CHECKSUM 2 hex}
   ```

즉 집중장치는 `R` 명령 하나를 보내면 **정확히 (1 + 요청한 리더 수)개**의 응답 프레임이
올 것을 기대하면 된다 — 이 개수만큼 받으면 그 게이트웨이 차례는 끝난 것으로 보고 바로
다음 게이트웨이로 넘어가도 된다(고정 딜레이로 기다릴 필요 없음). 프레임 하나에 다 몰아
넣지 않고 여러 개로 쪼갠 이유는, 응답 하나가 너무 길어져서 그 시간 동안 게이트웨이의
`loop()`가 오래 묶이는 걸 피하기 위해서다.

두 응답 다 체크섬은 `:ID:`부터 마지막 `:`까지 전체 XOR.

## 폴링 주기 / 명령 간격 (집중장치 설계 시 참고 — 실측 전 추정치)

**아직 실물 보드로 측정한 값이 아니다** — 실측 전까지는 아래를 출발점으로 삼고,
하드웨어 붙는 대로 재보정할 것.

19200bps ≈ 바이트당 약 0.52ms(8N1 가정)로 계산하면:

| 항목 | 길이 | 대략 전송 시간 |
|---|---|---|
| 명령 프레임 | 12바이트(개행 포함) | ~6ms |
| 상태 응답 프레임 | 24바이트 | ~13ms |
| 리더 상태 프레임(UID 없을 때/있을 때) | 34~56바이트 | ~18~29ms |

여기에 리더 1개당 실제 스캔 시간(`PCD_Init()` + 카드 감지 시도, 아직 벤치 미측정 —
MFRC522 특성상 각 수 ms 단위로 추정)을 더해야 한다. 리더 10개 전부(`READERIDX='A'`)
요청하면 전송+스캔 합쳐서 **게이트웨이 한 대당 대략 수백 ms** 걸릴 것으로 추정 — 세그먼트
하나에 게이트웨이가 최대 20대까지 물릴 수 있다는 `docs/architecture.md` 기준을 그대로
적용하면, **버스 전체를 한 바퀴 도는 데 수 초가 걸릴 수 있다.**

이걸 줄이는 현실적인 방법 하나: **문이 닫혀 있는 게이트웨이는 리더 상태가 바뀔 수가
없다**(슬롯에 손이 안 닿으니까). 집중장치가 각 게이트웨이의 마지막 상태 프레임으로
"지금 문이 열려 있는지"를 이미 알고 있으므로, **닫혀 있는 게이트웨이는 리더 전체
스캔(`READERIDX='A'`) 대신 어쩌다 한 번만 확인하고, 열려 있는 게이트웨이 위주로 자주
폴링**하는 식으로 버스 대역폭을 열려 있는(=지금 사람이 조작 중인) 곳에 몰아줄 수 있다.
이건 집중장치(`gateway-bridge`) 쪽 스케줄링 로직 설계 시 반영할 사항이라 지금 펌웨어
쪽에서 할 일은 없다.

## Fail-secure (통신 두절 대응)

마지막으로 유효한 LOCK 명령을 받은 지 `COMMS_TIMEOUT_MS`(현재 5000ms, `door_lock.h`)가
지나면 게이트웨이는 서버 명령과 무관하게 **무조건 잠금 상태로 전환하고 로컬 OPEN_BTN도
무시**한다. 행정반에 별도 비상 물리키가 있다는 전제로 확정(2026-09-01) — 통신 장애 시
현장 편의보다 보안(정보 유출/도난 방지)을 우선한다.

## 개선/TODO

- [x] XOR 체크섬 1바이트 추가
- [x] RFID를 "이벤트"에서 "요청-응답 상태 조회"로 재설계(2026-09-02)
- [x] 게이트웨이 ID를 그룹+DIP 4글자로 확장(2026-09-02)
- [x] 자동 하트비트 제거 + 브로드캐스트+R 무시 — 버스 충돌 최소화(2026-09-02)
- [ ] **폴링 주기/명령 간격 실측** — "폴링 주기/명령 간격" 절의 수치는 아직 추정치.
      실물 보드로 리더 스캔 1회 실제 소요시간부터 재야 한다.
- [ ] **집중장치의 "4글자 원시ID → 최종 gateway_id" 매핑 캐시가 아직 없음** — 미등록
      장치는 원시ID 그대로 `/api/ingest/events`에 실어서(`detected_gateways`에 자동 로그되게)
      보내고, 관리자가 매칭하면 그 결과를 집중장치가 어떻게 다시 받아와 캐시할지(주기적
      조회? 등록 API가 브리지에 알림?)는 다음 단계에서 설계.
- [ ] 타임아웃/재전송 규칙 — 집중장치(`gateway-bridge`) 쪽 미구현, 다음 단계
- [ ] RESET 필드를 실제 재부팅/재초기화 로직에 연결
- [ ] **집중장치(`gateway-bridge`)의 상태 diff → check_in/check_out 로직 자체가 아직 없음**
      — 지금 이 펌웨어가 보내는 `:RD:...:PRESENT:...:UID:...` 응답을 실제로 받아서
      리더별 마지막 상태와 비교해 전환을 만드는 코드가 다음 단계. 서버 쪽 확장(예: "타 내무반
      보관 중" 같은 교차 판정)은 이 diff 로직이 만드는 이벤트를 서버 이벤트 관리가 추가로
      해석하는 식으로 이어가면 된다.
- [ ] Concentrator가 파싱 직후 만들어야 하는 표준 이벤트 JSON 스키마는 `docs/architecture.md`
      5장 예시 + `backend/src/services/ingestService.js`가 받는 `{kind, gateway_id, ...}`
      형태를 그대로 따르면 됨 — 새로 설계할 필요 없음, 이미 백엔드가 확정한 스펙

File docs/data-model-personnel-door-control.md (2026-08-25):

# 인원/RFID 매핑 · 개폐 정책 · 판정 이벤트 데이터 모델

> `architecture.md` 6장(데이터 계층 재설계)의 후속 문서. `001_init.sql`(기지/건물/방/게이트웨이/원본 이벤트)에 이어,
> "누가 어느 폰을 보관 중인가"와 "언제 열려야/잠겨야 하는가"를 다루는 스키마를 정리한다.

## 도메인 정리

- **보관함(내무반 1개당 1대)** = `gateways` 1행. RFID 리더 10개(5개×2단), 뒷면 아두이노 PCB. 도어락/부저 제어와 RFID 리더 정보 수집을 담당하며, 시리얼로 `concentrators`("데이터수집장치")에 전달한다.
- **서버 → 게이트웨이**: 도어 제어 정보(정책)를 내려주고, 게이트웨이는 열림 버튼 입력을 이 정책과 대조해서 실제 개폐를 결정한다(버튼을 누른다고 무조건 열리는 게 아니라, 로컬에 들고 있는 최신 정책 상태와 비교).
- **게이트웨이 → 수집장치**: RFID 리더 정보, 스마트폰 RFID, 도어 열림/닫힘 상태 → 각각 `rfid_events`/`door_events`(001_init.sql, append-only)에 대응.
- **시각(`occurred_at`) 태깅 주체는 게이트웨이가 아니라 수집장치(concentrator)** — 보관함(게이트웨이)은 시각 정보를 보내지 않고, 수집장치가 이벤트를 받은 시점의 자기 시계로 태깅해서 서버에 전달한다. `backend/src/services/ingestService.js`는 이미 `event.occurred_at`이 오면 그 값을 그대로 쓰고, 없을 때만 서버 수신 시각(`new Date()`)으로 대체하도록 되어 있어 이 흐름과 맞음 — `gateway-bridge`(수집장치 쪽 코드) 구현 시 이 필드에 자기 시계 기준 시각을 ISO 8601(+타임존 오프셋 또는 `Z`)로 채워 보내면 된다.
- **스마트폰 RFID는 인원(군인) 1명과 1:1**. 인원 정보 = 이름/군번(고유식별)/전화번호/소속(내무반).

## 대시보드 상태 판정 (장비 상태 기준 → 인원 기준으로 확장)

기존 3단계 모니터링 대시보드는 인원-RFID 매핑이 없던 시점이라 "게이트웨이 온라인 여부/이벤트 건수" 같은 장비 상태 기준으로 구현했다. 아래 모델이 갖춰지면 원래 의도한 인원 기준 상태로 확장한다.

- **전체 등록 수**: `personnel` 행 수 (RFID 매칭 완료 기준)
- **보관중**: 등록된 RFID가 자기 소속 내무반 게이트웨이에서 최근 감지됨
- **부재**: 등록됐는데 지금 어디서도 감지 안 됨(평시)
- **이상**: 지금이 정책상 "잠겨있어야 하는 시간대"인데 없음 — `door_schedules` 기준으로 판정
- **미등록**: 리더에 감지된 RFID인데 `personnel`에 매핑이 없음
- **타 내무반 보관 중**: 감지는 됐는데, 감지된 게이트웨이의 내무반이 소속 내무반과 다름

이 중 부재/이상/미등록/타내무반은 원본 이벤트가 아니라 **판정 로직의 산출물**이라, 상태가 바뀔 때만 `personnel_status_events`에 기록해서 대시보드 하단 로그로 보여준다. (판정 엔진 자체의 구현은 이 문서의 범위가 아니라 이후 로드맵 항목 — 아래 "다음 단계" 참고.)

## 개폐 정책 (도어락 제어)

세 가지가 서로 다른 메커니즘이라 분리해서 설계한다.

1. **기본 정책**: 요일별 반복, 30분 단위. 편제(기지/건물) 또는 내무반 단위로 설정 가능. 미리 제공되는 참조 템플릿으로 언제든 쉽게 초기화(환원) 가능.
2. **실시간 설정**: 기본 정책 데이터 자체를 직접 수정 — 영구 반영.
3. **즉각 실행**: 정책과 무관하게 버튼 클릭으로 **최대 30분** 한시적으로 문을 열어주는 명령. 시간이 지나면 정책 상태로 자동 복귀.

설정 화면은 내무반별 "현재 적용 정책 상태"와 "실제 도어 열림/닫힘 상태"를 함께 보여줘야 한다. 도어 이벤트가 기대되는 시점에 들어오지 않는 경우(예: 정책상 개방 전환 시각인데 door_event가 없음)도 횟수/시간 임계값 기반으로 별도 이상 이벤트로 처리한다.

## 데이터 규모와 보존 전략

보관함 20개 × 리더 10개 = 200 슬롯, 5초 미만 주기로 수집되는 환경을 가정한다. RFID 인식은 물리적으로 불안정해서 — 실제로 보관 중이어도 특정 순간엔 못 읽고, 다른 리더는 정상 인식되는 경우가 발생한다. 그래서:

- **raw 이벤트(`rfid_events`/`door_events`)는 판정 로직 분석·개선용으로 일정 기간(예: 30~90일)만 보관**하고, 만료분은 아카이빙 배치로 정리한다(`001_init.sql` 주석에 이미 명시됨).
- **장기 보관은 인식 성공/실패 패턴을 재구성 가능한 요약 지표**로 축약한다 — 단순 카운트가 아니라 리더별 성공 횟수·최대 미인식 구간(gap)·흔들림(flap) 횟수까지 남겨서, raw 없이도 인식률 패턴을 분석할 수 있게 한다(`rfid_reader_daily_stats`).
- raw 테이블의 `occurred_at` 기준 월별 파티셔닝은 데이터가 실제로 쌓이기 시작할 때 별도 작업으로 진행한다(기존 001 테이블의 PK를 변경해야 해서 지금 단계에서는 보류).

## 스키마 (`backend/migrations/002_personnel_and_door_control.sql`)

```sql
-- 인원 및 스마트폰 RFID 1:1 매핑
CREATE TABLE IF NOT EXISTS personnel (
  service_number VARCHAR(20) PRIMARY KEY,       -- 군번
  name VARCHAR(50) NOT NULL,
  phone_number VARCHAR(20),
  room_code VARCHAR(30) NOT NULL,                -- 소속 내무반
  rfid_uid VARCHAR(32) UNIQUE,                   -- 매칭 전엔 NULL (등록 → 이후 매칭 흐름 지원)
  created_at DATETIME NOT NULL DEFAULT CURRENT_TIMESTAMP,
  FOREIGN KEY (room_code) REFERENCES rooms(room_code)
);

-- 도어 개폐 기본 정책 참조 템플릿 (미리 제공, 환원용)
CREATE TABLE IF NOT EXISTS door_schedule_templates (
  template_code VARCHAR(30) PRIMARY KEY,
  template_name VARCHAR(100) NOT NULL,
  week_slots JSON NOT NULL,                       -- {"mon":[bool*48], ..., "sun":[bool*48]} (30분 단위)
  created_at DATETIME NOT NULL DEFAULT CURRENT_TIMESTAMP
);

-- 실제 적용 중인 개폐 정책 (편제 또는 내무반 단위, "실시간 설정"이 수정하는 대상)
CREATE TABLE IF NOT EXISTS door_schedules (
  id INT AUTO_INCREMENT PRIMARY KEY,
  scope_type ENUM('base', 'building', 'room') NOT NULL,
  scope_code VARCHAR(30) NOT NULL,
  week_slots JSON NOT NULL,
  based_on_template VARCHAR(30),                  -- 환원 시 참조하는 템플릿
  updated_at DATETIME NOT NULL DEFAULT CURRENT_TIMESTAMP ON UPDATE CURRENT_TIMESTAMP,
  UNIQUE KEY uq_door_schedule_scope (scope_type, scope_code),
  FOREIGN KEY (based_on_template) REFERENCES door_schedule_templates(template_code)
);

-- 즉각 실행(임시 개방) 명령 — 정책과 무관, 만료 시각까지만 유효 (최대 30분)
CREATE TABLE IF NOT EXISTS door_overrides (
  id BIGINT AUTO_INCREMENT PRIMARY KEY,
  room_code VARCHAR(30) NOT NULL,
  door_command ENUM('open') NOT NULL DEFAULT 'open',
  starts_at DATETIME NOT NULL DEFAULT CURRENT_TIMESTAMP,
  expires_at DATETIME NOT NULL,
  requested_by INT,
  FOREIGN KEY (room_code) REFERENCES rooms(room_code),
  FOREIGN KEY (requested_by) REFERENCES users_admin(id),
  INDEX idx_door_overrides_room_active (room_code, expires_at)
);

-- 판정 결과 이벤트: 부재/이상/미등록/타내무반 — raw 센서 로그가 아니라 "상태 판정 로직"의 산출물
CREATE TABLE IF NOT EXISTS personnel_status_events (
  id BIGINT AUTO_INCREMENT PRIMARY KEY,
  status_type ENUM('absent', 'anomaly', 'unregistered_uid', 'wrong_room') NOT NULL,
  service_number VARCHAR(20),                     -- 미등록 UID 케이스는 NULL
  rfid_uid VARCHAR(32),
  room_code VARCHAR(30),                          -- 감지된 위치(타내무반 판정에 사용)
  detail JSON,
  occurred_at DATETIME NOT NULL DEFAULT CURRENT_TIMESTAMP,
  FOREIGN KEY (service_number) REFERENCES personnel(service_number),
  INDEX idx_status_events_type_time (status_type, occurred_at)
);

-- 장기 보관용: 리더별 일간 인식률 요약 (raw rfid_events 만료분을 롤업 후 아카이빙하는 배치가 채움)
CREATE TABLE IF NOT EXISTS rfid_reader_daily_stats (
  stat_date DATE NOT NULL,
  gateway_id VARCHAR(40) NOT NULL,
  reader_index TINYINT NOT NULL,
  read_success_count INT NOT NULL DEFAULT 0,
  max_gap_seconds INT,                            -- 해당 리더가 가장 오래 미인식이었던 구간(초)
  flap_count INT NOT NULL DEFAULT 0,               -- 인식↔미인식 전환 횟수("흔들림")
  PRIMARY KEY (stat_date, gateway_id, reader_index),
  FOREIGN KEY (gateway_id) REFERENCES gateways(gateway_id)
);
```

### 설계 근거

- `door_schedules`를 `scope_type`+`scope_code`로 일반화해서 편제(기지/건물)·내무반 어느 단위든 같은 테이블로 표현한다. 실제 적용 정책 조회 시 내무반 → 건물 → 기지 순으로 우선순위 조회(상속)하면 된다.
- `door_overrides`는 정책 테이블과 완전히 분리한다 — "실시간 설정"(정책 데이터 수정)과 "즉각 실행"(한시적 오버라이드)이 서로 다른 메커니즘이라는 걸 스키마 레벨에서 명확히 한다.
- `personnel_status_events`는 `rfid_events`/`door_events`(원본 센서 로그)와 별개의 2차 판정 로그다. 원본 위에서 판정 로직(디바운스, 정책 대조)을 돌려서 상태가 바뀔 때만 기록하는 구조다.

## 이번 스키마에 포함하지 않은 것 (알아두되 나중 단계로 미룸)

- `rfid_events`/`door_events` **월별 파티셔닝** — 기존 001 테이블의 PK를 변경해야 해서 더 위험한 작업. 데이터가 실제로 쌓이기 시작할 때 진행.
- **아카이빙 배치 작업** 자체 — 스키마만 준비, 구현은 추후.
- **게이트웨이 → 서버 인입(ingestion) API**와 `middlewares/bridgeAuth.js`(`backend/src/app.js`에 이미 TODO로 존재) — `rfid_events`/`door_events`를 실제로 채워 넣는 통로. 다음 단계에서 서버→게이트웨이 정책 전달(다운로드)과 함께 설계한다.

## 다음 단계 로드맵

| 단계 | 내용 | 비고 |
|---|---|---|
| A | 게이트웨이 브리지 인입 API + `middlewares/bridgeAuth.js` | rfid_events/door_events를 실제로 채우는 통로. 서버→게이트웨이 정책 전달도 이때 같이 설계 |
| B | 인원(personnel) 등록/조회/RFID 매칭 화면 | 레거시의 "미등록 RFID 매칭" 2단계 흐름 참고 |
| C | 상태 판정 엔진 + 대시보드 확장 | 보관중/부재/이상/미등록/타내무반, `personnel_status_events` 기록 로직 |
| D | 개폐 정책 관리 화면 | 기본 정책 템플릿, 편제/내무반 스코프별 실시간 설정, 즉각 실행(≤30분), 상태 확인 화면 |
| E | 이벤트 로그 조회 화면 | raw + `personnel_status_events` 통합 조회/필터 |
| F | 보존/아카이빙 배치 + 파티셔닝 | 데이터 실제로 쌓이기 시작하면 |

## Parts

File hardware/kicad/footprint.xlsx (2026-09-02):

지정자 | 부품 | 정격/값 | 추천 KiCad 풋프린트 | 출처
A1 | Arduino 보드 | Arduino_UNO_R3 | Connector_Arduino:Arduino_UNO_R3 | Root
BZ1 | 피에조 부저 | Buzzer | Buzzer_Beeper:PUI_Audio_SMT-0940-S-R(SMD) 또는 THT 2핀 | S6
C1 | 전해커패시터 | 100uF/25V | Capacitor_THT:CP_Radial_D6.3mm_P2.50mm | S1
C2 | 세라믹커패시터 | 0.1uF | Capacitor_SMD:C_0805_2012Metric | S1
C3 | 세라믹커패시터 | 10uF | Capacitor_SMD:C_1206_3216Metric | S1
C4 | 세라믹커패시터 | 22uF | Capacitor_SMD:C_1210_3225Metric | S1
C5 | 세라믹커패시터 | 10uF | Capacitor_SMD:C_1206_3216Metric | S1
C6 | 세라믹커패시터 | 22uF | Capacitor_SMD:C_1210_3225Metric | S1
C7 | 세라믹커패시터 | 0.1uF | Capacitor_SMD:C_0805_2012Metric | S3
C9 | 세라믹커패시터 | 0.1uF | Capacitor_SMD:C_0805_2012Metric | S4
C10 | 세라믹커패시터 | 0.1uF | Capacitor_SMD:C_0805_2012Metric | S4
C11~C14 | 세라믹커패시터 ×4 | 100nF | Capacitor_SMD:C_0805_2012Metric | S5
D1 | 쇼트키 다이오드 | SS54 (5A/40V) | Diode_SMD:D_SMB | S1
D2 | 정류 다이오드 | 1N4007 | Diode_THT:D_DO-41_SOD81_P10.16mm | S2
D3 | 양방향 TVS | SMAJ14CA | Diode_SMD:D_SMA | S1
D4 | 소신호 다이오드 | 1N4148 | Diode_SMD:D_SOD-123 | S4
F1 | 폴리퓨즈 | 2A | Fuse:Fuse_1812_4532Metric | S1
J1 | DC 배럴잭 | Barrel_Jack | Connector_BarrelJack:BarrelJack_CUI_PJ-102AH_Horizontal | S1
J2 | 4핀 커넥터 | Conn_01x04_Socket | Connector_JST:JST_XH_B4B-XH-A_1x04_P2.50mm | S2
J3 | 2핀 커넥터 | Conn_01x02_Socket | Connector_JST:JST_XH_B2B-XH-A_1x02_P2.50mm | S2
J4 | 2핀 커넥터 | Conn_01x02_Socket | TerminalBlock:TerminalBlock_bornier-2_P5.08mm | S3
J_MFC_1~10 | 8핀 커넥터 ×10 | Conn_01x08_Socket | Connector_PinSocket_2.54mm:PinSocket_1x08_P2.54mm_Vertical | S5
Q1 | P채널 MOSFET | PMOSFET | Package_TO_SOT_SMD:SOT-23 | S1
Q2 | N채널 로직레벨 MOSFET | IRLZ44N | Package_TO_SOT_THT:TO-220-3_Vertical | S2
Q3 | NPN 트랜지스터 | 2N3904 | Package_TO_SOT_SMD:SOT-23 | S1
Q4 | NPN 트랜지스터 | 2N3904 | Package_TO_SOT_SMD:SOT-23 | S4
R1 | 저항 | 10K | Resistor_SMD:R_0805_2012Metric | S1
R2 | 저항 | 10K | Resistor_SMD:R_0805_2012Metric | S1
R3 | 저항 | 10K | Resistor_SMD:R_0805_2012Metric | S2
R4 | 저항 | 220Ω | Resistor_SMD:R_0805_2012Metric | S2
R5 | 저항 | 22Ω | Resistor_SMD:R_0805_2012Metric | S3
R6 | 저항 | 22Ω | Resistor_SMD:R_0805_2012Metric | S3
R7 | 저항 | 10K | Resistor_SMD:R_0805_2012Metric | S3
R8 | 저항 | 120Ω | Resistor_SMD:R_0805_2012Metric | S3
R9 | 저항 | 10K | Resistor_SMD:R_0805_2012Metric | S3
R10 | 저항 | 1M | Resistor_SMD:R_0805_2012Metric | S4
R11 | 저항 | 10K | Resistor_SMD:R_0805_2012Metric | S4
R12 | 저항 | 220Ω | Resistor_SMD:R_0805_2012Metric | S6
R13 | 저항 | 33Ω | Resistor_SMD:R_0805_2012Metric | S5
R14~R21 | 저항 ×8 | 10K | Resistor_SMD:R_0805_2012Metric | S6
R22 | 저항 | 33Ω | Resistor_SMD:R_0805_2012Metric | S5
R23 | 저항 | 33Ω | Resistor_SMD:R_0805_2012Metric | S5
R25~R32 | 저항 ×8 | 33Ω | Resistor_SMD:R_0805_2012Metric | S5
R33, R34 | 저항 ×2 | 33Ω | Resistor_SMD:R_0805_2012Metric | S5
SW1 | 전압 선택 스위치 |  |  | S2
SW2 | DIP 스위치(1P) | SW_DIP_x01 | Button_Switch_THT:SW_DIP_SPSTx01_Slide_9.78x4.72mm_W7.62mm_P2.54mm | S3
SW3 | 스위치(1P) | VCC485BiasSW | Button_Switch_THT:SW_SPDT_PCM12 | S3
SW4 | DIP 스위치(1P) | SW_DIP_x01 | Button_Switch_THT:SW_DIP_SPSTx01_Slide_9.78x4.72mm_W7.62mm_P2.54mm | S3
SW5, SW6 | DIP 스위치 ×2 | SW_DIP_x04 | Button_Switch_THT:SW_DIP_SPSTx04_Slide_9.78x10.72mm_W7.62mm_P2.54mm | S6
U1 | DC-DC 벅컨버터 | MP2307DN | Package_SO:SOIC-8_3.9x4.9mm_P1.27mm | S1
U2 | 3.3V LDO | AMS1117-3.3 | Package_TO_SOT_SMD:SOT-223-3_TabPin2 | S1
U3 | RS485 트랜시버 | MAX13487E | Package_SO:SOIC-8_3.9x4.9mm_P1.27mm | S3
U4 | 보조 감시 MCU | ATtiny13A-P | Package_DIP:DIP-8_W7.62mm(소켓 자리) | S4
U5 | 8bit PISO 시프트레지스터 | 74HC165 | Package_SO:SOIC-16_3.9x9.9mm_P1.27mm | S6
U6, U7 | 3:8 라인 디코더 ×2 | 74LVC138A | Package_SO:SOIC-16_3.9x9.9mm_P1.27mm | S5
U8 | 쿼드 트라이스테이트 버퍼 | 74LVC125A | Package_SO:SOIC-14_3.9x8.7mm_P1.27mm | S5
U9 | 단일 트라이스테이트 버퍼 | 74AHCT1G125 | Package_TO_SOT_SMD:SOT-23-5 | S5

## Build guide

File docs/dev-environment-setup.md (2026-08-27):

# 개발 환경 구축 가이드 (Windows, 다른 PC에서 동일하게 세팅하기)

이 레포는 GitHub(`https://github.com/taegyunkim-kcp/smartvault`)에 올라가 있으므로, 새 PC에서는
"레포를 처음부터 만드는 것"이 아니라 **클론해서 세팅**하면 됩니다. 인터넷이 되는 일반 PC 기준(winget/설치파일)
설치 절차입니다 — 실제 부대 폐쇄망 배치는 별도 단계/별도 PC에서 진행합니다.

## 0. 설치 순서 요약

1. Git for Windows
2. VS Code
3. Claude Code (네이티브 설치 + VS Code 확장)
4. Node.js LTS
5. Python 3.x
6. Docker Desktop (WSL2 백엔드) — 개발/운영 DB를 컨테이너로 분리

---

## 1. Git for Windows

https://git-scm.com/download/win 에서 설치. 기본 옵션 그대로 진행해도 됩니다.
Claude Code가 Windows 네이티브 셸에서 Bash 도구를 쓰려면 Git for Windows가 필요합니다.

## 2. VS Code

https://code.visualstudio.com/ 에서 설치. 기본 옵션 그대로 진행하면 됩니다.
(에디터는 필수는 아니지만, 아래 Claude Code VS Code 확장을 쓰려면 먼저 설치돼 있어야 합니다.)

## 3. Claude Code 설치

PowerShell을 **관리자 권한 아닐 필요 없음**, 그냥 일반 PowerShell 열어서:

```powershell
irm https://claude.ai/install.ps1 | iex
```

설치 후 터미널을 새로 열고:

```powershell
claude doctor
```

로 정상 설치를 확인합니다. Claude Pro/Max/Team/Enterprise 계정 또는 Console(API) 계정이 필요합니다.

**VS Code 확장(선택, 권장)**: VS Code Extensions 마켓플레이스에서 "Claude Code" 검색해 설치하면
VS Code 통합 터미널/사이드바에서 바로 Claude Code를 띄울 수 있습니다. 확장 없이도 `claude`는
VS Code의 통합 터미널에서 그냥 실행하면 자동으로 IDE 연동(열린 파일·선택 영역 인식 등)이 됩니다.

## 4. Node.js LTS

https://nodejs.org 에서 LTS 버전 설치 (백엔드 Express, 프론트엔드 React 빌드에 필요).
설치 후 확인:

```powershell
node -v
npm -v
```

## 5. Python 3.x

https://www.python.org/downloads/windows/ 에서 설치. **설치 시 "Add python.exe to PATH" 체크 필수** (게이트웨이 브리지 실행에 필요).

```powershell
python --version
```

## 6. Docker Desktop

https://www.docker.com/products/docker-desktop/ 에서 설치, WSL2 백엔드로 설정.
설치 이유: 개발용 DB와 운영용 DB를 완전히 분리된 컨테이너로 띄워서, 개발 중 실수로 운영 데이터를 건드릴 위험을 원천 차단합니다.

```powershell
docker --version
docker compose version
```

---

## 7. 레포 클론 + 초기 설정

원하는 위치에 GitHub에서 클론합니다 (예: `C:\dev\smartvault`).

```powershell
cd C:\dev
git clone https://github.com/taegyunkim-kcp/smartvault.git
cd smartvault
```

**`.env.*` 파일은 git에 안 올라가 있습니다**(`.gitignore`에 포함, 시크릿이라 의도적으로 제외). 새 PC에서는
아래처럼 `.env.example`을 복사해서 새로 채워야 합니다 — 기존 PC의 값을 그대로 옮길 필요는 없고,
새 값(특히 `JWT_SECRET`)을 새로 생성해도 됩니다. 개발용 DB 비밀번호만 `docker-compose.dev.yml`에 적힌
값과 일치시키면 됩니다.

### 백엔드

```powershell
cd backend
copy .env.example .env.development
# .env.development 파일을 열어서 DB_PASSWORD, JWT_SECRET, BRIDGE_API_KEYS 값을 채우세요.
# DB_PASSWORD는 docker-compose.dev.yml의 MYSQL_PASSWORD와 동일해야 합니다.
npm install
```

### 프론트엔드

```powershell
cd ../frontend
copy .env.example .env.development
# VITE_API_BASE_URL=http://localhost:4000 그대로 두면 됩니다(백엔드 개발 포트).
npm install
```

### 게이트웨이 브리지

```powershell
cd ../gateway-bridge
python -m venv venv
venv\Scripts\activate
pip install -r requirements.txt
copy .env.example .env
# .env 파일을 열어서 CONCENTRATOR_ID, SERIAL_PORT 등을 실제 값으로 채우세요.
```

---

## 8. 개발 모드로 띄우기

```powershell
# 1) 개발용 DB 컨테이너 기동
cd C:\dev\smartvault
docker compose -f docker-compose.dev.yml up -d

# 2) 스키마 적용 (최초 1회 — migrations 폴더의 파일을 번호 순서대로 전부 적용)
docker exec -i smartvault-dev-db mysql -u smartvault_dev -pktg0506@! smartvault_dev < backend\migrations\001_init.sql
docker exec -i smartvault-dev-db mysql -u smartvault_dev -pktg0506@! smartvault_dev < backend\migrations\002_personnel_and_door_control.sql
docker exec -i smartvault-dev-db mysql -u smartvault_dev -pktg0506@! smartvault_dev < backend\migrations\003_gateway_reported_lock_state.sql
docker exec -i smartvault-dev-db mysql -u smartvault_dev -pktg0506@! smartvault_dev < backend\migrations\004_org_groups.sql
docker exec -i smartvault-dev-db mysql -u smartvault_dev -pktg0506@! smartvault_dev < backend\migrations\005_detected_gateways.sql
docker exec -i smartvault-dev-db mysql -u smartvault_dev -pktg0506@! smartvault_dev < backend\migrations\006_global_door_schedule.sql
docker exec -i smartvault-dev-db mysql -u smartvault_dev -pktg0506@! smartvault_dev < backend\migrations\007_door_override_lock_command.sql
docker exec -i smartvault-dev-db mysql -u smartvault_dev -pktg0506@! smartvault_dev < backend\migrations\008_status_event_acknowledgement.sql
docker exec -i smartvault-dev-db mysql -u smartvault_dev -pktg0506@! smartvault_dev < backend\migrations\009_door_policies.sql
# 009 적용 직후, 아래 1회성 스크립트로 기존 door_schedules 데이터를 door_policies/door_policy_scopes로 이관합니다.
node backend\scripts\migrate-door-schedules-to-policies.js
# 화면(보관함 개폐 관리/제어)에서 정책이 그대로 보이는지 확인한 뒤에만 010을 적용하세요(구 테이블을 지웁니다).
docker exec -i smartvault-dev-db mysql -u smartvault_dev -pktg0506@! smartvault_dev < backend\migrations\010_drop_door_schedules.sql
# 이후 새 마이그레이션이 추가되면 같은 방식으로 번호 순서대로 적용하면 됩니다 (자동 마이그레이션 도구는 아직 없음).

# 3) 백엔드 (포트 4000, 코드 수정 시 자동 재시작)
cd backend
npm run dev

# 4) 프론트엔드 (포트 3000, 별도 터미널)
cd frontend
npm run dev
```

`http://localhost:4000/health` 접속해서 `{"status":"ok","env":"development"}` 나오면 백엔드 정상.

### 데모 데이터로 화면 테스트하기

모니터링 대시보드/개폐 시간표 화면을 실제 데이터 없이도 눌러보며 확인할 수 있도록, 대량 데모 데이터를 채워주는 스크립트가 있습니다.

```powershell
cd backend
npm run seed:demo         # 기지 2개, 내무반 10개, 인원 100명(RFID 90 매칭/10 미매칭), 탐지·개폐 이벤트 생성
npm run seed:demo:clean   # 재생성 없이 데모 데이터만 삭제(원복)
```

- 재실행해도 안전합니다(멱등) — `seed:demo`를 다시 돌리면 이전 데모 데이터를 지우고 새로 채웁니다.
- 생성/삭제 대상은 `base_code`가 `2CORPS`/`3CORPS`인 데이터, 군번이 `26-2000xxx`인 인원, `DEMO-UID-*` RFID로 한정되어 있어 기존에 등록해둔 실제 데이터(예: `1base`/`1CORPS`)는 건드리지 않습니다.
- 자세한 생성 규칙(방 배치, 매칭/미매칭 비율, 상태 시뮬레이션 확률 등)은 `backend/scripts/seed-demo-data.js` 참고.

---

## 9. "운영" 모드로 같은 PC에서 띄우기

개발과 운영을 **완전히 다른 포트·다른 DB**로 분리해서 동시에 켜둘 수 있습니다.

```powershell
# 1) 운영용 DB 컨테이너 (dev와 별개 볼륨/포트)
copy .env.example .env.production   # backend 폴더 안에서, 값은 운영용으로 채움 (DB_PORT=3308 등)
docker compose --env-file .env.production -f docker-compose.prod.yml up -d

# 2) 운영 스키마 적용 (migrations 폴더 파일을 번호 순서대로 전부 적용 — 개발과 동일한 방식)
docker exec -i smartvault-prod-db mysql -u <운영유저> -p<운영비번> smartvault_prod < backend\migrations\001_init.sql
docker exec -i smartvault-prod-db mysql -u <운영유저> -p<운영비번> smartvault_prod < backend\migrations\002_personnel_and_door_control.sql
docker exec -i smartvault-prod-db mysql -u <운영유저> -p<운영비번> smartvault_prod < backend\migrations\003_gateway_reported_lock_state.sql
docker exec -i smartvault-prod-db mysql -u <운영유저> -p<운영비번> smartvault_prod < backend\migrations\004_org_groups.sql
docker exec -i smartvault-prod-db mysql -u <운영유저> -p<운영비번> smartvault_prod < backend\migrations\005_detected_gateways.sql
docker exec -i smartvault-prod-db mysql -u <운영유저> -p<운영비번> smartvault_prod < backend\migrations\006_global_door_schedule.sql
docker exec -i smartvault-prod-db mysql -u <운영유저> -p<운영비번> smartvault_prod < backend\migrations\007_door_override_lock_command.sql
docker exec -i smartvault-prod-db mysql -u <운영유저> -p<운영비번> smartvault_prod < backend\migrations\008_status_event_acknowledgement.sql
docker exec -i smartvault-prod-db mysql -u <운영유저> -p<운영비번> smartvault_prod < backend\migrations\009_door_policies.sql
# .env.production으로 backend/scripts/migrate-door-schedules-to-policies.js 실행(NODE_ENV=production node ...) 후 확인, 그 다음에만:
docker exec -i smartvault-prod-db mysql -u <운영유저> -p<운영비번> smartvault_prod < backend\migrations\010_drop_door_schedules.sql
```

운영 백엔드는 터미널을 계속 열어두지 않도록 **PM2**로 상시 구동합니다:

```powershell
npm install -g pm2
cd backend
pm2 start src/app.js --name smartvault-backend-prod --env production
pm2 save
pm2 startup   # 안내에 따라 Windows 부팅 시 자동 시작 등록 (선택)
```

운영 프론트엔드는 빌드 후 정적 파일을 서빙합니다 (예: `serve` 패키지):

```powershell
cd frontend
npm run build
npx serve -s dist -l 3001
```

### 개발/운영 상태 한눈에 확인

```powershell
docker ps                 # dev-db(3307), prod-db(3308) 둘 다 떠 있는지
pm2 list                  # 운영 백엔드 프로세스 상태
```

---

## 10. Claude Code로 작업 시작하기

VS Code에서 `smartvault` 폴더를 열고, 통합 터미널(`` Ctrl+` ``)에서:

```powershell
claude
```

또는 VS Code 밖에서 그냥 PowerShell로:

```powershell
cd C:\dev\smartvault
claude
```

레포에 이미 `docs/architecture.md`(아키텍처), `docs/data-model-personnel-door-control.md`(인원/RFID/개폐
데이터 모델), 이 문서(`docs/dev-environment-setup.md`)가 들어있어서 Claude Code가 새 PC에서도 곧바로
참고할 수 있습니다. `frontend/.claude/skills/run-frontend/`도 그대로 따라오므로, Playwright만 설치하면
(`cd frontend && npm install -D playwright && npx playwright install chromium`) 프론트엔드 화면 검증도
기존 PC와 동일하게 쓸 수 있습니다.

**작업 지시할 때 팁**: "백엔드에 gateways CRUD API 만들어줘" 처럼 레이어 이름(routes/services/repositories)을
명시하면 이 레포 구조를 그대로 따라서 코드를 넣어줍니다.

---

## 체크리스트

- [ ] Git, VS Code, Claude Code, Node.js, Python, Docker Desktop 설치 완료
- [ ] `claude doctor` 정상
- [ ] 레포 클론 완료 (`git clone` — `git init` 아님, 이미 GitHub에 있는 레포)
- [ ] 백엔드/프론트엔드 `.env.development` 각각 새로 채움(커밋 안 됨 확인: `git status`에 안 뜨는지)
- [ ] 개발 DB 컨테이너 기동 + 마이그레이션 001~005 전부 적용
- [ ] 백엔드 `/health` 정상 응답
- [ ] 프론트엔드 dev 서버 기동
- [ ] (선택) `npm run seed:demo`로 화면 테스트용 데모 데이터 생성
- [ ] (운영 준비되면) `.env.production` 채움, prod DB 컨테이너 별도 기동, PM2로 백엔드 상시 구동

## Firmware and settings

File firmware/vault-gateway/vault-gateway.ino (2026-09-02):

// SmartVault 보관함 게이트웨이(Arduino UNO) 펌웨어 — v0 초안
//
// 핀맵: pins.h (근거: hardware/CLAUDE.md 1장)
// 프로토콜: firmware/docs/protocol-spec.md + rs485_link.cpp
// Fail-secure 정책: door_lock.h 상단 주석 참고 (통신 두절 시 무조건 잠금, 로컬 버튼 무시 —
// 행정반 비상 물리키 존재를 전제로 확정됨, 2026-09-01)
//
// 레거시 참고(Z:\HDD2\스마트폰보관함\1. 일반\mcuProgram\ver1_2_1_close_reading_only_white_MCU_20250204):
// LOCK_STATE 극성/개방 펄스 길이(2000ms)/버튼-닫힘 가드는 그 코드에서 그대로 가져왔다.
// 다만 리더 CS 방식(그쪽은 리더당 GPIO 10개, 이 보드는 74LVC138A 디코더)과 통신 프레임
// 포맷(그쪽은 가변 구분자, 여기는 고정 길이+체크섬)은 새 보드/명세에 맞춰 새로 짰다 —
// architecture.md가 말한 "로직은 유지, 구조는 재설계" 원칙 그대로.
// 내장 AVR 워치독(wdt_enable/wdt_reset)도 레거시에서 가져온 것 — hardware/CLAUDE.md 5장의 외부
// ATtiny13A 워치독과는 별개 레이어다: 내장 WDT는 "RS485 선로가 조용하면 칩 스스로
// 2초 뒤 리셋"(레거시와 동일 임계값), ATtiny13A는 "칩 자체가 응답을 안 하는 경우"까지
// 잡아내는 바깥쪽 안전망 — 두 개가 서로 대체하지 않고 같이 있어야 한다.
//
// RFID 스캔은 두 경로로 나뉜다(2026-09-02):
// 1) rs485_link — 집중장치가 READEROP='R'로 물어볼 때만 스캔+응답. 서버 보고용, 문
//    상태와 무관하게 동작. check_in/check_out 판단은 안 하고 현재 상태만 보고한다.
// 2) presence_watch — 문이 열려 있는 동안 게이트웨이가 스스로 훑으며, 빈 자리에 폰이
//    새로 놓이는 순간에만 확인 부저를 울린다(뺄 때는 무음). RS485/서버와 완전히 무관한
//    로컬 로직이라 통신이 끊겨 있어도 동작한다 — 그게 이 경로를 따로 둔 이유다.

// 아직 안 된 것(다음 단계):
// - ATtiny13A 워치독 펌웨어는 완전히 별도(ISP로 직접 굽는 별개 프로젝트) — 여기 포함 안 함
// - buzzer.cpp의 개방/오류 톤은 placeholder(카드 인식 멜로디는 레거시 값을 그대로 포팅함)
// - RESET(전체 재부팅류) 명령 필드는 파싱만 하고 아직 실제 동작에 연결 안 함
//   (rs485_link.cpp의 (void)resetScope 참고)
// - gateway-bridge 쪽: 리더 상태 응답을 받아 check_in/check_out으로 전환하는 로직 미구현

#include <avr/wdt.h>
#include "pins.h"
#include "device_id.h"
#include "rfid_mux.h"
#include "rs485_link.h"
#include "door_lock.h"
#include "buzzer.h"
#include "presence_watch.h"

// AVR 워치독의 잘 알려진 함정: WDT가 리셋을 일으키면 MCUSR의 WDRF 비트가 켜진 채로
// 남는데, 이걸 안 지우고 setup()에서 다시 wdt_enable()하면 부트로더가 sketch로 넘어오는
// 그 짧은 시간 안에 또 리셋이 걸려서 무한 리셋 루프에 빠질 수 있다. 레거시 코드에도 이
// 방어 코드가 없었다 — 여기서는 표준 권장 패턴대로 setup() 맨 앞에서 바로 지운다.
void earlyClearWatchdogFlag() __attribute__((naked, used, section(".init3")));
void earlyClearWatchdogFlag() {
  MCUSR = 0;
  wdt_disable();
}

void setup() {
  Serial.begin(115200); // D0/D1은 배선 안 된 예비 핀 — RS485(SoftwareSerial)와 별개, USB 디버그 전용

  deviceId_setup();
  doorLock_setup();
  buzzer_setup();
  rfidMux_setup();
  presenceWatch_setup();
  rs485_setup(deviceId_get());

  // 내장 워치독: RS485 선로에 2초 넘게 아무 바이트도 안 들어오면 칩을 스스로 리셋한다
  // (레거시와 동일 임계값). 리셋 뒤에도 door_lock의 fail-secure는 "부팅 후 아직 명령 못
  // 받음"으로 계속 잠금 상태를 유지하므로 안전하게 맞물린다.
  wdt_enable(WDTO_2S);

  Serial.print(F("vault-gateway boot, dip=0x"));
  Serial.print(deviceId_get(), HEX);
  Serial.print(F(", gateway_id="));
  Serial.println(rs485_getMyGatewayId());
}

void loop() {
  // 게이트웨이는 명령 없이 스스로 아무것도 안 보낸다(자동 하트비트 없음, 2026-09-02
  // 제거) — 여러 게이트웨이가 같은 RS485 버스를 쓰는데, 각자 독립된 타이머로 자동
  // 전송하면 서로 다른 게이트웨이의 전송이 겹쳐서 충돌할 수 있기 때문이다. 도어
  // 상태는 rs485_link.cpp가 READEROP='R' 응답 맨 앞에 실어서만 보낸다.
  if (rs485_loop()) {
    wdt_reset();
  }
  doorLock_loop();
  presenceWatch_loop();
}

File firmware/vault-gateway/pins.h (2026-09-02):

#ifndef VAULT_GATEWAY_PINS_H
#define VAULT_GATEWAY_PINS_H

#include <Arduino.h> // uint8_t / A0~A5 등 아두이노 핀 매크로 — 이 헤더 혼자 include돼도 되게

// 핀맵의 유일한 근거는 hardware/CLAUDE.md 1장(Arduino UNO 핀맵 확정)이다.
// 회로/핀맵이 바뀌면 hardware/CLAUDE.md를 먼저 고치고, 그 다음 이 파일을 맞춘다 — 반대 순서 금지.

// RFID 리더 CS 선택용 74LVC138A 디코더 (U6=SS_1~8 / U7=SS_9~10, BANK로 상호배타 전환)
constexpr uint8_t PIN_DEC_A = 2;
constexpr uint8_t PIN_DEC_B = 3;
constexpr uint8_t PIN_DEC_C = 4;
constexpr uint8_t PIN_BANK = 8;

// RS485 (MAX13487E, AutoDirection — DE/RE 제어 불필요, SoftwareSerial)
constexpr uint8_t PIN_485_RX = 5;
constexpr uint8_t PIN_485_TX = 6;

// 부저 (BZ1 직접 구동)
constexpr uint8_t PIN_BUZZ = 7;

// MFRC522 공통 SPI + RST (레벨시프트는 하드웨어에서 처리, 펌웨어는 그냥 표준 SPI 핀 사용)
constexpr uint8_t PIN_RFID_RST = 9;
// D11=MOSI, D12=MISO, D13=SCK — 표준 SPI 핀이라 <SPI.h>가 자동으로 씀, 별도 상수 불필요.
// MFRC522 라이브러리에 넘기는 "SS 핀"은 실제로 배선되지 않은 더미 핀이다 — 실제 리더 선택은
// PIN_DEC_A/B/C + PIN_BANK 조합으로 미리 해두고, 그 상태를 유지한 채로 라이브러리를 호출한다.
// (74LVC138A 출력이 active-low라 디코더 주소 자체가 SS 역할을 대신함 — rfid_mux.cpp 참고)
constexpr uint8_t PIN_RFID_DUMMY_SS = 10; // 배선 없음(디코더 전환으로 해제된 예비 핀 재사용)

// 도어락
constexpr uint8_t PIN_OPEN_BTN = A0;   // INPUT_PULLUP, 로컬 개방 버튼
constexpr uint8_t PIN_OPEN_CTL = A1;   // 도어락 구동 제어(Q2 게이트)
constexpr uint8_t PIN_LOCK_STATE = A2; // INPUT_PULLUP, 도어 상태 감지

// 장치 ID (74HC165 + DIP 스위치 8비트)
constexpr uint8_t PIN_DEV_ID = A3; // Q7 시리얼 출력
constexpr uint8_t PIN_DEV_PL = A4; // PL(SH/LD, 래치)
constexpr uint8_t PIN_DEV_CP = A5; // CP(클럭)

// RFID 리더 개수/디코더 주소 범위
constexpr uint8_t RFID_READER_COUNT = 10;
constexpr uint8_t RFID_BANK_A_COUNT = 8; // BANK=0: SS_1~8 (U6)
// BANK=1: SS_9~10 (U7, 디코더 주소 0~1만 유효)

#endif

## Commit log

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2026-08-24 feat(backend): 게이트웨이 CRUD API 추가
    routes/services/repositories 3계층으로 gateways 테이블에 대한
    생성/조회/수정/삭제 API를 구현. room_code FK, gateway_id 중복 등
    DB 제약 위반을 400/404/409 응답으로 매핑한다.
2026-08-24 feat(frontend): 앱 골격 + 게이트웨이 관리 화면 추가
    Vite 기본 데모를 걷어내고 관리자 대시보드 골격(헤더/사이드바 3그룹/
    라우터)을 구성. 사이드바는 레거시 프로토타입의 모니터링/이벤트 처리/
    등록 및 관리 구조를 유지하되, 백엔드 API가 아직 없는 항목은 준비 중
    placeholder로 연결. 기존 /api/gateways CRUD와 1:1로 연결되는
    게이트웨이 관리 화면(목록/필터/생성/수정/삭제)을 구현.
    앱을 실제로 구동/검증하기 위한 run-frontend 스킬(Playwright 기반
    드라이버)도 함께 추가.
2026-08-24 feat(backend): 기지/건물/방 편제 관리 CRUD API 추가
    bases/buildings/rooms 각각에 대해 게이트웨이 API와 동일한
    routes/services/repositories 3계층 패턴을 반복 적용. 자연키(코드)와
    상위 조직 FK는 생성 시에만 정해지고 이후 불변이며, 수정(PUT)은
    이름(*_name)만 바꿀 수 있다 — 코드 네이밍 관례상 재배치를 허용하면
    코드와 실제 상위 조직이 어긋나는 문제를 피하기 위함.
2026-08-24 feat(frontend): 편제 관리(중대/소대/내무반) 화면 추가
    bases/buildings/rooms에 대한 목록/생성/수정 화면을 게이트웨이
    List/Form 패턴 그대로 반복 구현. 사이드바 "등록 및 관리" 그룹에
    중대/소대/내무반 관리 메뉴 추가. 게이트웨이 목록 필터와 등록 폼의
    room_code 자유 입력을 이제 생긴 방 목록 API 기반 드롭다운으로 교체.
    공용 CRUD 스타일을 pages/gateways/gateways.css에서
    src/styles/crud.css로 옮겨 4개 리소스가 공유하도록 정리
    (.gateway-form → 범용 .crud-form).
    run-frontend 드라이버에 select 명령 추가 — 네이티브 <select>를
    click+화살표키로 조작하면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
2026-08-24 feat(backend): 모니터링 대시보드 집계 API 추가
    기지/건물/방 계층별로 게이트웨이 수·온라인 게이트웨이 수(최근 5분
    이내 last_seen_at)·최근 24시간 rfid_events 건수를 집계하는 읽기 전용
    API 3개(GET /api/dashboard/{bases,buildings,rooms})를 추가. 방 단위
    응답에는 최신 door_events 상태도 포함.
    여러 테이블을 조인하는 집계라 리소스 하나에 매이지 않으므로 기존
    CRUD 3계층과 별도로 dashboardRepository/Service/routes를 신설.
    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
2026-08-24 feat(frontend): 모니터링 대시보드(중대/소대/내무반 드릴다운) 추가
    사이드바 "전체 현황"(placeholder였던 인덱스 라우트)을 실제
    드릴다운 대시보드로 교체. 중대 목록 → 소대 목록 → 내무반 목록
    3단계를 breadcrumb으로 오가며, 각 계층에서 게이트웨이 온라인/오프라인
    배지와 최근 24시간 이벤트 수를 보여준다. 내무반 단계에는 최신 문
    열림/닫힘 상태도 표시.
    crud.css에 .badge-online/.badge-offline/.breadcrumb/.empty-state
    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
2026-08-25 feat(backend): 인원/RFID 매핑·개폐정책·판정이벤트 스키마 추가
    사용자와의 도메인 설명(보관함 하드웨어 구조, 개폐 정책 3종 구분,
    RFID 인식 신뢰성/데이터 보존 요구사항)을 바탕으로 5개 테이블을
    신설: personnel(인원-RFID 1:1), door_schedule_templates/
    door_schedules(편제·내무반 단위 주간 반복 정책 + 환원용 템플릿),
    door_overrides(정책과 분리된 ≤30분 즉각 개방), personnel_status_events
    (부재/이상/미등록/타내무반 판정 로그), rfid_reader_daily_stats
    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
2026-08-25 feat(backend): 게이트웨이 브리지 인입 API + 개폐 정책 조회 API 추가
    브리지 인증 미들웨어(bridgeAuth, X-Bridge-Api-Key를 BRIDGE_API_KEYS와
    대조)를 app.js의 기존 TODO 자리에 연결하고, 두 API를 추가:
    - POST /api/ingest/events: rfid/door 이벤트 배치 수신, rfid_events/
    door_events에 적재하고 대상 게이트웨이 last_seen_at을 하트비트로
    갱신. 존재하지 않는 gateway_id는 건너뛰고 나머지는 계속 처리
    (inserted/skipped 카운트 반환) — 브리지가 재전송 루프를 도는 걸
    전제로 부분 실패가 전체를 막지 않게 함.
    - GET /api/bridge/policy?room_code=: 방에 적용되는 개폐 정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
2026-08-25 feat(gateway-bridge): local_queue 오프라인 재전송 큐 구현
    config.py/local_queue.py의 기존 TODO 주석대로 init_db/enqueue/flush
    구현. flush()는 미전송 이벤트를 오래된 순으로 모아 백엔드의
    POST /api/ingest/events로 한 번에 전송하고, 성공 시에만 sent=1로
    마킹한다 — 실패하면 그 자리에서 중단해 다음 주기에 그대로 재시도된다.
    실제 시리얼 파싱(serial_client.py 등)은 firmware 쪽 프로토콜 명세가
    아직 확정 전이라 이번 범위에서 제외.
2026-08-25 feat(backend): 인원 CRUD + RFID 매칭 API 추가
    personnel 테이블에 대한 CRUD(routes/services/repositories 3계층,
    게이트웨이 패턴 재사용)를 추가. room_code는 전입/전출로 실제 바뀔 수
    있어 수정 가능하게 열어두되, rfid_uid는 일반 수정 API로 못 건드리게
    막고 전용 매칭/해제 엔드포인트(POST·DELETE /api/personnel/:sn/match)
    로만 바꾸도록 분리했다.
    GET /api/rfid-tags/unmatched는 rfid_events에 감지 기록은 있지만
    personnel에 매핑되지 않은 UID를 최근 감지 위치와 함께 반환 —
    프론트 매칭 화면의 데이터 소스.
2026-08-25 feat(frontend): 사용자 등록 + RFID 매칭 화면 추가
    기존 "사용자 등록" placeholder를 실제 목록/생성/수정 화면으로
    교체(게이트웨이 List/Form 패턴 재사용, room_code는 편집 가능). RFID
    매칭 화면은 레거시 프로토타입의 NewUserDectected.jsx(미등록 사용자 ↔
    미매칭 감지 태그를 나란히 두고 페어링) 흐름을 참고해 좌/우 라디오
    선택 + 매칭 버튼으로 구현.
    crud.css에 두 컬럼 선택 리스트 스타일(.match-columns/.match-item)
    추가. 목록 새로고침 함수를 useEffect와 클릭 핸들러 양쪽에서 재사용할
    때 set-state-in-effect 린트 규칙을 피하려면 effect 안에서 익명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
2026-08-25 fix(backend): mysql2 풀에 UTC 타임존 고정
    DB 컨테이너는 항상 UTC로 뜨는데, mysql2 기본 설정은 Date 객체를
    Node 프로세스의 로컬 타임존(개발 PC는 KST)으로 포맷해서 저장한다 —
    INTERVAL 계산이나 요일/시간대 비교처럼 "DB가 보는 지금 시각"과
    비교하는 로직이 9시간씩 어긋나는 조용한 버그였다. 게이트웨이
    인입(A단계)의 rfid_events/door_events.occurred_at 저장, 그리고
    이번에 만드는 개폐 정책 시간대 판정에서 실제로 재현 확인.
    timezone: 'Z'로 고정해서 Node↔DB 양쪽 다 UTC로 통일.
2026-08-25 feat(backend): 인원 상태 판정 엔진 추가 (보관중/부재/이상/타내무반)
    GET /api/dashboard/personnel-status: 매칭된 인원마다 최신 rfid_event로
    보관중/타내무반을 가르고, 감지가 없으면 소속 내무반의 유효 개폐
    정책(A단계 doorPolicyService 재사용)이 지금 잠김 시간대인지로
    부재/이상을 가른다. 미등록은 B단계에서 만든 rfid-tags/unmatched를
    그대로 재사용.
    실시간 이벤트 스트림/스케줄러가 없어 이번에도 "요청 시점에 계산"
    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
2026-08-25 feat(frontend): 대시보드에 인원 현황 요약 + 이상 이벤트 로그 추가
    "전체 현황" 페이지 상단에 요약 카드 6개(전체 등록/보관중/부재/이상/
    타내무반/미등록)를 추가 — 이상·타내무반·미등록은 경고색. 카드를
    클릭하면 해당 상태의 인원(또는 미등록 태그) 목록이 아래 인라인으로
    펼쳐진다(레거시 page1.jsx의 "부재 클릭 → 로그 모달" 아이디어를
    별도 모달 없이 단순화). 기존 3단계 중대별 게이트웨이 장비 상태
    테이블은 그대로 유지하고, 맨 아래에 최근 이상 이벤트 로그를 추가.
    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
2026-08-25 fix(backend): 즉각실행 취소 직후 active_override 경합 수정
    findActiveOverride가 NOW() BETWEEN starts_at AND expires_at(양끝 포함)를
    썼는데, 취소(door_overrides.cancel)는 expires_at을 그 순간의 NOW()로
    당긴다. MySQL DATETIME은 초 단위라 취소 직후 같은 초 안에 재조회하면
    방금 취소한 오버라이드가 여전히 "활성"으로 보이는 경합이 있었다
    (D단계 프론트 검증 중 브라우저에서 실제로 재현). expires_at > NOW()
    (엄격 부등호)로 바꿔서 해결.
2026-08-25 feat(backend): 개폐 정책 템플릿/실시간 설정/즉각 실행 쓰기 API 추가
    A단계(조회 전용 doorPolicyService)와 C단계(판정 유틸 doorScheduleUtil)
    위에 관리자가 실제로 정책을 쓰는 쪽을 추가:
    - door_schedule_templates CRUD — 기본 정책 참조 템플릿(게이트웨이
    패턴 3계층 재사용). week_slots 유효성 검증(요일 7개×boolean 48개)을
    doorScheduleUtil.assertValidWeekSlots로 분리해 C단계 isLocked()와
    같은 "week_slots 형태" 정의를 공유.
    - door_schedules — PUT으로 스코프별 upsert(실시간 설정), POST .../reset
    으로 템플릿 복사(환원), DELETE로 상위 상속 폴백. 상속 계산 자체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
2026-08-25 feat(frontend): 개폐 시간표 관리 화면 추가
    정책 템플릿 관리(목록/생성/수정), 개폐 시간표 관리(기지/건물/방
    스코프 선택 → 현재 적용 정책+실제 도어 상태 표시 → 요일×30분 그리드로
    실시간 설정/환원/삭제 → 방 단위 즉각 실행)를 추가.
    WeekSlotGrid 공용 컴포넌트(요일 7행×30분 48열, 칸 클릭 토글·요일
    클릭으로 하루 전체 토글)를 새로 만들고, 상수/헬퍼(DAY_KEYS 등)는
    react-refresh의 "컴포넌트 파일은 컴포넌트만 export" 규칙 때문에
    components/weekSlots.js로 분리.
    run-frontend 드라이버로 템플릿 생성→환원→즉시개방→취소까지 직접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
2026-08-25 feat(backend): 이벤트 로그 조회 API 추가 (rfid/door/판정)
    GET /api/events/{rfid,door,status} — room_code/gateway_id/기간(from,to)
    필터 + limit/offset 페이지네이션. COUNT 쿼리 없이 limit+1건을 가져와
    마지막 1건을 잘라내는 방식으로 has_more만 판단(personnelStatus/
    doorOverride 리포지토리에서 이미 쓰던 "검증된 정수를 SQL에 직접
    바인딩" 패턴 재사용 — LIMIT/OFFSET 플레이스홀더 대신).
    판정 이벤트(status)는 C단계에서 만든 personnel_status_events에
    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
2026-08-25 feat(frontend): 이벤트 로그 조회 화면 추가
    RFID/도어/판정 3개 탭 + 내무반·기간(판정 탭은 상태유형도) 필터 +
    "더 보기" 페이지네이션. 마지막 남은 ComingSoonPage placeholder(이벤트
    로그)를 실제 화면으로 교체하면서, 더 이상 어디서도 참조되지 않는
    ComingSoonPage.jsx 자체를 삭제.
2026-08-25 feat(backend): 게이트웨이 개폐 설정 상태 보고 수집
    게이트웨이가 스스로 보고하는 "지금 어떤 잠금 설정을 적용 중인지"를
    받는 인입 이벤트 종류(kind: 'lock_status')를 추가. 서버가 정책으로
    계산한 값(A단계 door_schedules)과는 별개 축이라 gateways 테이블에
    last_seen_at과 같은 성격의 스냅샷 컬럼 2개(reported_lock_state,
    reported_lock_state_at)를 추가하고, 방 단위 대시보드 요약에도 방에
    속한 게이트웨이들 중 최신 보고값을 상관 서브쿼리로 붙였다(기존
    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
2026-08-25 feat(frontend): 모니터링·개폐 시간표 화면에 게이트웨이 개폐 설정 상태 표시
    게이트웨이 관리 목록에 "개폐 설정" 컬럼, 모니터링(내무반 단위) 화면에
    "개폐 설정" 배지, 개폐 시간표 관리 화면에 "게이트웨이 보고 설정"을
    추가 — 서버가 계산한 정책/도어 센서값과 나란히 보여줘서 관리자가
    직접 비교할 수 있게 한다. SchedulePage는 이미 door 상태를 가져오려고
    호출하던 getRoomSummaries 응답을 그대로 재사용(API 추가 호출 없음).
2026-08-25 feat(frontend): 모니터링·시간표 화면에 전체 내무반 개폐 현황 표시
    드릴다운(중대→소대→내무반) 없이도 전체 내무반의 문 상태/개폐 설정을
    한 화면에서 볼 수 있어야 한다는 요청 반영.
    - DashboardBasesPage("전체 현황"): "전체 내무반 개폐 상태" 표를
    중대별 게이트웨이 현황과 최근 이상 이벤트 사이에 추가
    (getRoomSummaries() 무필터 호출 — 백엔드는 이미 building_code
    없이도 전체 방을 반환하도록 돼 있어 API 변경 불필요).
    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
2026-08-25 feat(frontend): 전체 내무반 현황을 색상 타일 그리드로 교체
    텍스트 표 대신, 방마다 작은 색상 타일 하나로 여러 내무반을 한눈에
    식별할 수 있게 했다: 타일 배경색=개폐 설정(회색 잠김/주황 열림 허용/
    점선 미보고), 우측 상단 점=문 상태(초록 열림/회색 닫힘/점선 기록
    없음). 평소엔 내무반 이름 대신 순번(정렬 순서)만 표시하고, 커서를
    올리면 title 툴팁으로 전체 room_code/이름을 보여준다 — 이름이 길어도
    타일 크기가 깨지지 않는다.
    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
2026-08-25 feat(backend): 방 요약에 서버 계획(scheduled) 개폐 상태 추가
    지금까지 방 요약(GET /api/dashboard/rooms)엔 게이트웨이가 보고한
    설정 상태와 문 센서 상태만 있었고, "서버 스케줄이 지금 이 순간
    잠겨있어야 한다고 계산한 값"은 빠져 있었다. A단계 doorPolicyService
    + C단계 doorScheduleUtil.isLocked를 그대로 재사용해 방마다
    scheduled_lock_state(locked/unlocked/정책없음)를 계산해서 붙인다
    — personnelStatusService가 이미 쓰던 것과 같은
    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
2026-08-25 feat(frontend): 사용자 등록 화면에서 RFID 해제 가능하도록 추가
    인원 수정 화면에 현재 매칭된 RFID UID를 표시하고 "RFID 해제" 버튼으로
    매칭을 해제할 수 있게 함. 기존 backend unmatch API(DELETE /api/personnel/:id/match)를
    그대로 재사용 — rfid_uid가 NULL이 되면 personnelStatusService가 해당 인원을
    매칭 대상에서 제외해 자연히 "RFID 미매핑" 상태로 표시됨.
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2026-08-25 feat(frontend): 조직 구성 트리 화면 통합 + 게이트웨이 탐지-매칭 UI
    - 중대/소대/내무반 관리 3개 분리 페이지를 OrgStructurePage(/org) 하나로 통합 —
    상위 조직 라벨까지 포함해 트리로 보여주고 클릭으로 확장, 노드별 추가/수정/삭제.
    하위 추가 시 코드 입력값을 상위 코드로 자동 프리필(OrgNodeModal).
    기존 api/bases.js·buildings.js·rooms.js(REST 클라이언트)는 그대로 재사용 —
    SchedulePage/DashboardByBasePage 등의 드롭다운 데이터 소스는 영향 없음.
    - GatewayListPage에 "탐지된 미등록 게이트웨이" 섹션 추가 — 내무반을 지정해
    매칭하면 정식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
2026-08-25 docs: 다른 PC에서 개발 환경 세팅하는 절차로 개발 가이드 갱신
    - git init(최초 스캐폴드) 대신 GitHub 레포 git clone 기준으로 변경
    - VS Code 설치 + Claude Code VS Code 확장 절차 추가
    - 프론트엔드 절차를 "Vite 프로젝트 생성"(스캐폴드 전 상태 기준, 지금은 stale)에서
    npm install + .env.development 세팅으로 수정
    - 스키마 적용 명령을 001 하나만이 아니라 지금 있는 마이그레이션(001~005) 전부
    순서대로 적용하도록 수정, DB 비밀번호도 docker-compose.dev.yml과 일치하는 값으로 수정
    - frontend/.env.example 신규 추가(지금까지 없었음 — backend와 동일한 패턴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
2026-08-27 fix: 마이그레이션 번호 충돌 해소 (006 → 008)
    다른 PC에서 push된 006_global_door_schedule.sql / 007_door_override_lock_command.sql과
    번호가 겹쳐서 008로 재번호. dev-environment-setup.md 적용 순서도 006~008 전부 반영.
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2026-08-27 fix: 정책 삭제/편집/임시정책 UX 개선 + 임시정책 저장 시각 반올림 경합 수정
    - 정책 삭제를 멤버 존재 여부와 무관하게 허용(자동 기본 정책 복귀)
    - 정책 카드 자체 타임테이블에서 다중 슬롯 선택 후 한 번에 임시정책 적용
    (기존 대비 칸 클릭마다 확인창이 뜨던 방식 제거), 상속으로만 연결된
    방을 다른 정책으로 드래그해도 명시적으로 이동되도록 수정
    - 카드에서 만든 임시정책은 같은 카드에 인라인(영구 내용과 다른 칸만
    주황 diff)으로 표시하고, 별도 UI로 만든 임시정책은 계속 별도 카드로 표시
    - 시간 헤더 클릭 단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
2026-08-27 fix: 내무반 타일 즉각 실행의 만료 시각을 슬롯 경계로 서버에서 직접 계산
    내무반 타일 클릭으로 만드는 즉각 실행은 프론트에서 "슬롯 끝까지 남은 분"을
    분 단위로 반올림해 duration_minutes로 넘기고 있었는데, 클릭 시점마다 반올림
    오차가 다르고 그 값을 다시 서버쪽 NOW()에 더하다 보니 같은 정책 안에서
    여러 방을 연달아 클릭하면 만료 시각이 서로 달라졌다. duration_minutes를
    생략하면 서버가 지금 슬롯(30분)이 끝나는 절대 시각을 SQL로 직접 계산해서
    저장하도록 바꿔, 같은 슬롯 안에서는 언제 클릭하든 항상 같은 만료 시각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
2026-08-27 fix: 정책 카드와 내무반 타일의 상태 표시가 서로 어긋나던 문제 수정
    - SchedulePage의 reloadPolicies가 정책 목록만 갱신하고 내무반 타일용
    allRooms는 최초 로드 때만 불러온 뒤 갱신하지 않아, 드래그 이동/멤버
    추가·제거/임시정책 적용·취소 뒤에도 타일이 예전 상태를 계속 보여주던
    문제 수정 — reloadPolicies에서 allRooms도 같이 다시 불러오게 함
    - getEffectivePolicy(방 단위 실제 적용 내용 계산)가 room→building→base
    →global로 올라가다 영구 정책을 찾으면 그 자리서 멈춰서, 정책에 room
    단위로 직접 속한 방은 그 정책이 base/buildin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
2026-09-01 feat: 게이트웨이 펌웨어 초안 + 하드웨어 설계자료 등록
    펌웨어(firmware/vault-gateway/):
    - 핀맵/도어락/RFID/RS485/워치독 모듈 구현, 레거시 펌웨어(Z:\HDD2\스마트폰보관함)에서
    검증된 값(도어락 펄스 2000ms, 카드 인식 멜로디, 내장 AVR 워치독) 이식
    - Fail-secure 확정: 통신 두절 시 무조건 잠금 + 로컬 버튼 무시(행정반 비상키 전제)
    - RFID를 "새 카드 이벤트"가 아니라 "요청-응답 상태 조회"로 설계 — 슬롯에 계속 거치된
    폰도 실시간 파악 가능하게. check_in/check_out 판단은 집중장치가 담당
    - 문 열림 중에는 게이트웨이가 스스로 리더를 훑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
    [DEVid-Buzz.kicad_sch, DoorRock-drv.kicad_sch, MFRC522_Conn.kicad_sch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]
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2026-09-02 chore: KiCad 회로도 최신 변경사항 반영
    원본 작업 폴더가 "회로도 편집 완료/20260901_ver01"로 재구성됨(이전 smartvault-pcb-1
    경로는 더 이상 존재하지 않음). 하위 시트 6개 전부와 최상위 시트에 실제 설계 변경
    있음(DoorRock-drv는 축소, 최상위 시트는 대폭 확장 — 회로가 재구성된 것으로 보임).
    PCB 레이아웃 자체는 변경 없음. footprint.xlsx(부품-풋프린트 매핑) 신규 추가.
    파일 내부의 프로젝트명 자기참조는 원본 작업 파일명("20260901_ver01")이 아니라
    저장소 표준 이름("smartvault")으로 맞춰서 복사 — 작업 폴더 쪽 날짜/버전 파일명
    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
    [DEVid-Buzz.kicad_sch, DoorRock-drv.kicad_sch, MFRC522_Conn.kicad_sch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]
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
